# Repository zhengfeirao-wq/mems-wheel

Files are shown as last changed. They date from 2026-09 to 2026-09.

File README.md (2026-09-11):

# Tactile500 — 四板触觉采集系统（500 Hz / PyUSB）

500 Hz 四通道触觉传感采集系统，用于 AgiBot G1 机械爪。包含 **APM32F402 固件**与
**Python 上位机**两部分，通过 CH340 USB-UART 桥接，基于 V2 二进制协议通信。

---

## 仓库结构

```
.
├── upper_pyusb_500hz/        上位机：Python 库 + CLI + 浏览器监视界面
│   ├── src/tactile500/       核心库
│   ├── tests/                单元测试（含独立 C 编码向量）
│   ├── tools/                诊断与基准工具
│   ├── docs/                 接口、协议、发布说明
│   └── wheelhouse/           离线 wheel（tactile500 + pyusb）
│
├── firmware_tactile500/      APM32F402 固件
│   ├── Source/               应用逻辑（main / 传感器 / 协议 / 流控）
│   ├── Include/              配置与头文件
│   ├── Config/               DAL 板级配置
│   ├── Project/              Keil 工程（6 个板型 Target）
│   ├── docs/                 协议 V2、板型通道表
│   └── 烧录_OSR256_20260910/ 该档 OSR256 固件的 HEX 交付物与构建清单
│
├── outline/                  结构与点位
│   ├── 2d_sampling_points/   12 / 32 点传感器平面坐标（常量模块 + 原始 CSV + 坐标图）
│   └── 3d_structure/         夹爪三维结构（STEP / Blender / 可编辑预览 / 点位源）
│
├── docs/                     跨子项目文档
├── README_当前版本.md        版本入口索引
└── 今晚测试入口_嵌入式与wheel.md
```

---

## 硬件构型

四块独立采集板，每块通过一只 CH340（VID `1a86` / PID `7523`）接入主机：

| 板型 | 传感器点数 | 固件 identity | 说明 |
|---|---:|---|---|
| 左手 12 点（手指） | 12 | `0x08` | 无缆 |
| 右手 12 点（手指） | 12 | `0x09` | 无缆 |
| 左手 32 点（掌心） | 32 | `0x0E` | 短线 |
| 右手 32 点（掌心） | 32 | `0x0F` | 短线 |

另有长线旧版构型 `0x0C` / `0x0D`。

### 左右手如何区分

**左右手在烧录时确定，不是上电后自适应的。** `TACTILE_PROFILE` 是编译期宏，
由 Keil Target / GCC 构建目录选定，进而决定帧内的 `identity` 字节：

```
bit0    : 0=左手  1=右手
bit1    : 0=12点  1=32点
bit2    : 0=长线  1=短线（12点板恒为 0）
bit7:3  : 映射版本（当前 = 1）
```

固件每帧都携带该字节，上位机据此解出 `frame.role`
（`left_fingers` / `right_fingers` / `left_palm` / `right_palm`），
**不依赖 USB 端口位置**。USB 拓扑仅用于打开设备与诊断。

> ⚠️ 若把左右手固件烧反，上位机不会报错——它会按 USB 端口位置分配角色，
> 而 `identity` 会自相矛盾。现场联调时应用 `tactile500 scan` 核对该字节与物理位置。

---

## 协议要点（V2 / wire version `0x21`）

```
A5 5A | len | version | identity | status | sequence |
sample_time_us | fresh_mask | 温度×N(2B) | 压力×N(3B) | CRC16

12 点帧 =  80 字节      32 点帧 = 180 字节
UART   = 921600 8N1     帧率     = 500 Hz（周期 2 ms）
```

固件为**纯单向广播**：上电、等待约 1 秒完成传感器初始化，随后自动连续发送，
**不接收任何命令**（无握手、无校准写入）。

---

## 安装与运行（上位机）

主机需已安装 `libusb-1.0`。示例在新目录中执行，**不要覆盖机器人本体应用的虚拟环境**：

```bash
python3 -m venv .venv
.venv/bin/python -m pip install --no-index --find-links wheelhouse tactile500==0.4.2

.venv/bin/tactile500 scan                      # 只枚举，不打开设备
.venv/bin/tactile500 probe --seconds 30        # 收帧并报告实际速率
.venv/bin/tactile500 capture --seconds 1800 --output captures/run001
.venv/bin/tactile500 inspect captures/run001
.venv/bin/tactile500 view --bind 0.0.0.0 --port 8875 --output-root captures
.venv/bin/tactile500 view --simulate           # 无实物时的四板模拟
```

高速读取在已打开的 libusb1 后端上预提交 32 个异步 Bulk IN 请求。
该适配层使用 PyUSB 内部结构，**依赖固定为 `pyusb==1.3.1`**；
升级前须重新验证。同步读取可用于诊断对照：`TactileSystem(usb_io="sync")`。

---

## 接入上层系统

```python
from tactile500 import TactileSystem

system = TactileSystem()
native = system.subscribe(capacity=8192)
system.open()
try:
    while True:
        item = native.get(timeout=1.0)
        frame = item.frame
        # frame.role: left_fingers / right_fingers / left_palm / right_palm
        consume(frame.role, frame.sequence, frame.sample_time_us,
                frame.temperature, frame.pressure, frame.fresh_mask,
                item.host_read_end_ns)
finally:
    system.close()
    native.close()
```

需要同一时刻的四板快照时使用 `system.snapshots(hz=500, delay_seconds=0.004)`，
其状态为 `updated / reused / stale / missing / offline / ambiguous`。
快照采用同一主机单调时钟，不插值、不使用未来数据。

**单位说明**：`temperature` 为 0.1 °C；`pressure` 为旧固件的有符号 `raw * 9 / 80` 尺度，
**未经标定，不应称为 Pa 或 N**。

完整接口见 [`upper_pyusb_500hz/docs/API_AND_INTEGRATION.md`](upper_pyusb_500hz/docs/API_AND_INTEGRATION.md)，
二进制格式见 [`PROTOCOL_AND_RECORDING.md`](upper_pyusb_500hz/docs/PROTOCOL_AND_RECORDING.md)。

---

## 已知限制

以下为实测确认的边界，**读取与判别接口稳定可用**，但这些现象客观存在：

### 1. ~~`fresh_mask` 恒为 0~~ —— **已在 v3 固件修复**

> **状态更新（2026-09-11）：已修复并实机验证。** 四板 88 个通道全部恢复，
> `init_error` 归零，`fresh ≈ 0.5`（健康值）。详见
> [`firmware_tactile500/docs/DRDY修复与v3自愈记录.md`](firmware_tactile500/docs/DRDY修复与v3自愈记录.md)。
> 以下保留原分析作为背景。

原固件中 100% 的帧带 `not_all_fresh` 状态，`per_channel_fresh_fraction` 全为 0。
这意味着固件的 DRDY 轮询取不到「新转换」证据。

**这不等于断线或读数无效。** 判定依据是 `status` 的其它位：

| `fresh_mask` | `status` 其它位 | 含义 |
|---|---|---|
| 0 | 仅 `not_all_fresh` | SPI 通、传感器无故障、初始化成功；仅缺新鲜度证据 |
| 0 | 含 `spi_error` | SPI 通信故障 |
| 0 | 含 `sensor_error` | 传感器报故障（`ready & 0xFC`） |
| 0 | 含 `init_error` | 上电配置回读失败 |

**根因**：原固件初始化末尾写 `0xA5 = 0x88`，把 bit7 `DAC_on` 置 1。
按 NSA2302 datasheet Rev1.2 第 11 页，该位为 *Enable voltage output mode*；第 17 页 6.3 节说明
`DAC_on=1` 即进入 **analog output mode**（"no matter what 'CMD' registers contents"），
自主执行 64 次压力 + 1 次温度转换；而第 18–19 页 6.5.1 节的 INT/DRDY 行为只在
**命令驱动**的四种工作模式下定义。该模式不属于其中，故 DRDY 永不置位。

另有一个叠加因素：板载 EEPROM 被早期固件烧入了 `0xA5 = 0x88`，
上电自动加载后若固件的 `0xA5 = 0x08` 写入未生效，芯片会退回模拟输出模式，
此时 `0x30` 触发命令被忽略 —— v3 用**运行中自愈**（连续 4 帧 DRDY=0 即重写配置）解决。

**修复要点**：保持 `DAC_on=0`，改用 `0x30` COMMAND 寄存器触发单次转换，
做流水线采集（读完即触发下一轮，转换在帧间隔内完成），SPI 提至 3.75 MHz。
**协议与上位机均无需改动。**

### 2. `fresh ≈ 0.5` 是真实转换能力的反映，不是缺陷

NSA2302 在单次转换模式下一次完整转换（含每次 power-up）耗时 **2~4 ms**。
在 500 Hz 帧率下，因此每两帧才有一个真实新测量 —— `fresh` 比例约为 **0.5**。

这解释了早期"模拟输出模式"为何能到 ~489 次/秒：那是**自主连续转换、无每次上电开销**，
但代价是 DRDY 永不置位。**两者是本质权衡。**

若要每帧都是真实新测量，可把帧率降到 250 Hz；当前设计保留 500 Hz 帧率并用
`fresh_mask` 如实标记哪一帧是新数据。

### 3. 通道存在偶发满量程跳变

左手 12 点板（`identity 0x08`）的 **ch6** 出现 `±943718` 的跳变
（≈ 24 位满量程的符号异常），极差达 1,887,436。其余三板无此现象。

**软件基线扣除（校零）无法解决此问题**——已实测验证，减去静置均值后极差
改善率为 **0.0%**。因为校零只能平移波形，不能压缩幅度。该校零处理更适合
消除通道间静态偏置与温漂基线，不是此类数字异常的解法。

### 4. Hub 供电共担

Hub 由机器人 USB 总线供电。软件可隔离单设备通信故障，
**无法阻止物理短路导致整个 Hub 掉电**；如需该级别的故障隔离，
需要具备逐端口限流保护的供电硬件。

### 5. 跨板时间戳不可直接相减

MCU 时间戳各自从上电开始计。本版本固件不接收启动命令，
因此软件**无法让独立 MCU 的 ADC 硬件同时启动**。
4 ms 快照延迟提供选择缓冲，但不消除 USB 调度抖动或传感器转换相位差。

### 6. 平台验证范围

性能验证针对 **Ubuntu aarch64**（AgiBot G1 实机，Python 3.10）。
Windows USB 后端未验证。

---

## 测试

```bash
cd upper_pyusb_500hz
python -m pytest -q
```

覆盖独立 C 编码向量、CRC/碎片/噪声恢复、序号与时间戳回绕、
四板故障与换口、快照因果性、慢消费者与录制损坏检查。

固件侧另有 6 种板型的 GCC/Keil 双构建与 C 核心向量测试，
以及 12 份 HEX 的校验和 / Flash 范围 / 启动与中断向量检查。

---

## 部署到 AgiBot G1

```bash
cd ~
python3 -m venv .venv
.venv/bin/python -m pip install --no-index --find-links wheelhouse tactile500==0.4.2

.venv/bin/tactile500 scan
.venv/bin/tactile500 view --bind 0.0.0.0 --port 8875 --output-root captures
```

随后在 Windows 浏览器打开 `http://<G1地址>:8875`。

> G1 的当前日历时钟与工作电脑日期可能不一致。UTC 字段保留 G1 原始值；
> 所有速率、超时与软件对齐均使用单调时钟，不依赖该日历时间。

---

## 来源与许可

固件基于 Geehy APM32F4xx DAL 示例；厂商许可条款见
`firmware_tactile500/` 内相关声明文件。CH340 控制传输序列与传输基础类
来自已归档的旧版上位机项目；V2 解析、自动发现、故障隔离、快照与录制
为本项目实现。

本 Python 库**不依赖机械臂/机器人控制 SDK，也不发送运动命令**。

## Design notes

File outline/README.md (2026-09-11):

# outline

触觉夹爪的**二维采样点**与**三维结构模型**。

| 子目录 | 内容 |
|---|---|
| [`2d_sampling_points/`](2d_sampling_points/) | 12 点板 / 32 点板的传感器平面坐标：常量模块、原始 CSV、坐标图（PNG + Markdown）、绘图脚本 |
| [`3d_structure/`](3d_structure/) | 夹爪三维结构：STEP 结构件与装配体、Blender 模型与渲染图、可编辑预览（HTML/three.js）、几何校验数据 |

---

## 2d_sampling_points

传感器在平面上的采样点坐标，**12 点板与 32 点板各一套**。

| 文件 | 说明 |
|---|---|
| `sensor_coords.py` | **坐标常量模块**，上位机与可视化直接 `import`，无需解析 CSV |
| `coord_Big_raw.csv` | 32 点板原始坐标（`sensor_Number, X_coord, Y_coord`） |
| `coord_Small_raw.csv` | 12 点板原始坐标 |
| `传感器坐标图.md` | 坐标图文档：嵌入 PNG + 纯文本 ASCII 坐标图 + 逐行坐标表 + 结构分析 |
| `coord_plot_all.png` | 总览：两板单图 + 同坐标系叠加 |
| `coord_plot_big32.png` / `coord_plot_small12.png` | 单板大图 |
| `make_sensor_coords.py` | 生成器：CSV → `sensor_coords.py`（数值逐字照抄） |
| `plot_coords.py` | 绘图：常量 → PNG，并校验等比例与说明框不遮挡数据点 |
| `make_coord_md.py` | 生成器：常量 → `传感器坐标图.md` |

### 坐标约定

* **每块板的左下角 = (0, 0)**，Y 轴向上。平移量 = 该板自己的 `(x_min, y_min)`，**只平移，不缩放、不旋转、不镜像**。
* 两块板用的是同一套规则，因此对齐到同一原点后可以直接比较尺寸与节距。
* 原始绝对坐标（与 CSV 逐字一致）保留在 `sensor_coords.py` 的 `*_COORDS` / `*_XY` 里。

| 板 | 点数 | 平移量 | 原点化尺寸 宽 × 高 |
|---|---:|---|---|
| Big 32 点 | 32 | (127.531, 55.6552) | 42.4614 × 27.5869 |
| Small 12 点 | 12 | (105.8507, 71.1159) | 11.3550 × 29.9387 |

### 用法

```python
from sensor_coords import xy_rel_for, coords_rel_for, normalized_xy, size_for

xy_rel_for(17, 32)    # -> (0.0, 0.0)        Big 板左下角
xy_rel_for(23, 32)    # -> (42.4614, 8.975)  最远点
coords_rel_for(12)    # -> Small 板整张表
normalized_xy(32)     # -> {通道号: (u, v)}，u = X/宽, v = Y/高
normalized_xy(32, y_up=False)   # v=0 在上，屏幕坐标直接乘控件高度即可
```

重新生成（Python 3.10+，需要 matplotlib）：

```powershell
python make_sensor_coords.py     # CSV  ->  sensor_coords.py
python plot_coords.py            # 常量 ->  PNG（左下角 = (0,0)）
python plot_coords.py --raw      # 常量 ->  PNG（原始绝对坐标）
python plot_coords.py --flip     # 常量 ->  PNG（Y 轴向下）
python make_coord_md.py          # 常量 ->  传感器坐标图.md
python sensor_coords.py          # 常量模块自检
```

`plot_coords.py` 会逐面板校验**等比例**（`ratio` 必须为 `1.0000`）与**说明框是否遮挡数据点**（必须为 0 个）。

坐标数据源自 [`3d_structure/editable_gripper_preview/coordinates/`](3d_structure/editable_gripper_preview/coordinates/)，两处 `coord_*_raw.csv` 内容一致。

---

## 3d_structure

夹爪三维结构模型与可编辑预览。

| 项 | 说明 |
|---|---|
| `onebody-12-jiegoujian.STEP` / `onebody-32-jiegoujian.STEP` | 12 点 / 32 点结构件 STEP |
| `editable_gripper_preview/cad/12`、`cad/32` | 分件 STEP：结构本体、硅胶帽、盖板、连接器、PCB 示意，含装配体与爆炸图 |
| `editable_gripper_preview/blender/` | Blender 源文件（`.blend`）、`.glb` 与渲染 PNG |
| `editable_gripper_preview/gripper-preview.html` | 可交互三维预览（three.js，单文件、离线可用） |
| `editable_gripper_preview/mesh-data.json`、`geometry-validation.json` | 网格数据与几何校验结果 |
| `editable_gripper_preview/build_models.py`、`build_preview.py`、`verify_cad.py` | 建模与校验脚本 |
| `自适应通用夹爪传感器说明书.pdf` | 传感器说明书 |
| `baseline-manifest.json`、`README.md` | 基线清单与说明 |

### 打开预览

直接双击 `editable_gripper_preview/gripper-preview.html`（或拖进浏览器）即可，依赖已内置于 `vendor/`。

### 重新构建

```powershell
cd editable_gripper_preview
pip install -r requirements-cad.txt
python build_models.py
python build_preview.py
```

```powershell
python verify_baseline.py          # 校验基线清单
python editable_gripper_preview/verify_cad.py
```

---

## 备注

* 本目录按仓库 `.gitignore` 的规则**强制加入**了 `*.csv` 与 `__pycache__/`：前者是坐标数据源（必须入库），后者是 Python 编译缓存（如需清理见下）。
* 清理编译缓存：

  ```powershell
  git rm -r --cached outline/3d_structure/__pycache__ outline/3d_structure/**/__pycache__
  ```

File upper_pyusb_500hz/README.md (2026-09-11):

# Tactile500 V2 PyUSB 上位机（0.4.2）

**最新交接入口（2026-09-10）：[安装、接口示例与已知边界](../out/04_wheel交接/联调说明.md)，[两档数据和CH12报告](../out/README.md)。交接wheel仍为0.3.0，OSR256在固件侧设置；原始wheel未重打包。今晚有一次USB重新枚举后需要重启采集服务恢复，真实Hub热插拔尚不能承诺全部自动恢复。**（后续进展：0.4.1 交付软件校零 `tare.py`，0.4.2 起提供 `tare` 命令行，见 `docs/TARE.md`。）

面向 G1 Ubuntu / Python 3.10 的四板触觉采集库。仅通过 PyUSB + libusb 访问 CH340
（VID `1a86` / PID `7523`），不依赖 ttyUSB、pyserial 或 ch341 内核模块。

**今晚测试入口：[四板查看与 wheel 交付](docs/RELEASE_0_3_0.md)。**
同一 wheel 提供 Python API、命令行原始采集，以及可选的 Windows 浏览器四板界面。
界面以10Hz读取缓存，原始采集和录制按板卡实际帧率运行。未启动 view 时不启动HTTP线程。

当前协议：`A5 5A` V2，12 路 80 字节，32 路 180 字节。旧 `BT` 数据不能直接混入 V2。
V2 修订 `0x21` 修复了 APM32F402 普通 DMA 通道未关闭导致的约 125Hz 发送问题。
配套固件在相邻目录 `嵌入式代码/Applications/Tactile500`。

## 安装与运行

这是 `py3-none-any.whl`，可安装到 Ubuntu aarch64；机器需要已有 `libusb-1.0`。
高速读取在 PyUSB 已打开的 libusb1 后端上预提交 32 个异步 Bulk IN 请求，避免 Python
解析期间没有在途 USB 请求。此适配层使用 PyUSB 内部结构，依赖固定为 `pyusb==1.3.1`。
升级 PyUSB 前须重新验证该适配层；同步 PyUSB 读取可用 `TactileSystem(usb_io="sync")`
作诊断对照。本次性能验证针对 Ubuntu aarch64，未验证 Windows USB 后端。
本次 G1 实机已确认 libusb 可用、CH340 未绑定内核驱动、普通用户有 USB 访问权限。
不要覆盖现有机器人应用的虚拟环境。示例在一个新目录执行：

```bash
python3 -m venv .venv
.venv/bin/python -m pip install --no-index --find-links wheelhouse tactile500==0.4.2
.venv/bin/tactile500 scan
.venv/bin/tactile500 probe --seconds 30
.venv/bin/tactile500 capture --seconds 1800 --output captures/run001
.venv/bin/tactile500 inspect captures/run001
.venv/bin/tare --seconds 2 --note "第 1 天开机"   # 夹爪张开、无接触时采一次零点
# G1 上运行，Windows 访问 G1 当前地址的8875端口：
.venv/bin/tactile500 view --bind 0.0.0.0 --port 8875 --output-root captures
# 无实物时的四板模拟，界面明确标示模拟数据：
.venv/bin/tactile500 view --simulate
```

`tare` 是 0.4.2 起的独立命令（软件校零，`src/tactile500/tare.py`）：采一次静止基线、
打印零点 JSON、追加写入 `~/.tactile500/tare/journal.jsonl`。用法与退出码见
[docs/TARE.md](docs/TARE.md)。

`wheelhouse/` 同时提供本库和 PyUSB wheel。`scan` 只枚举；`probe/capture` 会配置
CH340 的 921600 8N1 和 DTR/RTS，然后读 Bulk IN，不向 MCU 发送启动或控制命令。
采集目录必须不存在，以防覆盖历史数据。Ctrl+C 会停止读取并排空录制队列。

若系统已有内核驱动或另一程序占用接口，本库报告该设备错误并持续重试，其他板继续工作。
权限配置属于实际操作系统部署事项；无需安装串口驱动，不自动抢占接口或复位 USB Hub。

## 接入大系统

原始帧订阅保持板子的真实发送频率。所有数组默认都是**固件已经排列好的通道顺序**。

```python
from tactile500 import TactileSystem

system = TactileSystem()
native = system.subscribe(capacity=8192)
system.open()
try:
    while True:
        item = native.get(timeout=1.0)
        frame = item.frame
        # frame.role: left_fingers / right_fingers / left_palm / right_palm
        consume(frame.role, frame.sequence, frame.sample_time_us,
                frame.temperature, frame.pressure, frame.fresh_mask,
                item.host_read_end_ns)
finally:
    system.close()
    native.close()
```

上层需要同一时刻的四板快照时：

```python
from tactile500 import TactileSystem

with TactileSystem() as system:
    for snapshot in system.snapshots(hz=500, delay_seconds=0.004):
        for role, slot in snapshot.slots.items():
            # state: updated / reused / stale / missing / offline / ambiguous
            if slot.value is not None:
                consume_snapshot(snapshot.target_ns, role, slot.state,
                                 slot.value.frame, slot.age_ns)
```

快照采用同一主机单调时钟，挑选目标时刻之前最近收到的帧，不插值、不用未来数据。
慢消费者跳过过期快照，`skipped_ticks` 记录跳过数量，不补发密集的历史快照。
`receive_skew_ns` 是选中帧的主机接收时间差，不是 ADC 采样同时性的证明。
MCU 的时间戳各自从上电开始，不能直接跨板相减；本版本没有 MCU 接收启动命令，
因此软件不能让独立 MCU 的 ADC 硬件同时启动。4ms 的快照延迟提供选择缓冲，
不能消除 USB 调度抖动或传感器自身转换相位差。

`frame.temperature` 单位为 0.1°C；`frame.pressure` 保留旧固件的有符号 `raw * 9 / 80`
尺度，未经额外标定不称为 Pa 或 N。`fresh_mask` 仅表示读取前看到了 DRDY 且读取成功。
实测修订 0x21 的连续 DAC 模式能读到变化数值，但 DRDY 始终为 0，因此该位当前无法证明
每个通道 500 次/秒新转换；0 不自动等于断线或读数无效。温度在此模式下刷新较慢。
硬件错误查看 SPI、sensor、init 位；主机断线/过期状态单独在 `system.status()` 中报告。

`TactileHand` 是 `TactileSystem` 的别名，便于使用旧入口名称。数据结构已改为 V2，
不承诺与旧 DeepSeek 的帧对象或 T500 录制格式兼容。完整接口见
[API_AND_INTEGRATION.md](docs/API_AND_INTEGRATION.md)。

## 自动识别、换口与隔离

- 从帧身份字节识别四个角色：左/右手 × 12/32 路；短/长线和映射修订随帧保留。
- USB 拓扑只用于打开设备和诊断。换 Hub 口后重新识别，不把旧口号当角色。
- 同角色两块板同时在线时报告 `ambiguous`，不任意选一块供上层使用；原始帧仍按路径录制。
- 每个设备独立 USB 读取线程和解析线程；持续重连，单板打开失败或拔出不停止其他板。
- 输入、订阅和录制队列均有上限；超过上限公开记录丢弃数量，不阻塞其他采集。
- Hub 当前由机器人 USB 总线供电。软件可以隔离单设备通信故障，无法阻止物理短路导致
  整个 Hub 掉电；若要求这种故障也隔离，需要具有逐端口限流保护的供电硬件。

32 路短线物理位置表沿用用户已确认的旧上位机表。调用
`tactile500.mapping.physical_values(frame)` 会同时变换温度、压力和 fresh 位。
长线物理布局未确认时拒绝自动转物理位置，仍可正常接收其固件通道顺序。
不要再次应用 MCU 的片选排列。

## 录制、测试与来源

录制文件保存原始 V2 字节、CRC、序号、MCU 时间戳以及主机读取时间。
`session.json` / `report.json` 保存丢包、坏帧、队列丢弃和运行状态。
起始截断候选与稳定流中的坏帧分别计数。G1 当前日历时钟与工作电脑日期不一致，
UTC 字段保留 G1 原始值；所有速率、超时和软件对齐都使用单调时钟，不依赖该日历时间。
具体二进制格式见 [PROTOCOL_AND_RECORDING.md](docs/PROTOCOL_AND_RECORDING.md)。

```bash
python -m pytest -q
python -m pip wheel --no-build-isolation --no-deps . -w wheelhouse
```

测试包括独立 C 编码向量、CRC/碎片/噪声恢复、序号与时间戳回绕、四板故障和换口、
快照因果性、慢消费者和录制损坏检查。实物结果与限制见 `reports/` 和验收报告。
四板模拟不能替代四块实物同时运行；已先后测试左12/左32短线和右12/右32长线两套。
OSR2048与OSR256的60秒主对比均来自同一套右12/右32长线，完整证据在上面的out入口。

来源：CH340 控制传输序列和传输基础类来自已归档的
`备份/旧版上位机/deepseek-tactile500_pyusb上位机`（相对本工作区主目录），
协议依据本项目 V2 固件；V2 解析、自动发现、故障隔离、快照与录制实现位于此目录。
原 DeepSeek 项目未被修改。该 Python 库不依赖机械臂/机器人控制 SDK，也不发送运动命令。

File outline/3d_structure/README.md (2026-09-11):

# 触觉夹爪模型 · 当前唯一版本

保留版本：**2026-09-08，房顶朝上、柔性导线伸直修正版**。PCB 与传感器已按两份 CSV 的实际 XY 相对位置重建，12 通道为 3/3/2/2/2 五排；胶层接触平面延伸至尖端的设计保留。12 通道和 32 通道是同一版本的两个型号，初始展示均为房顶朝上，导线按伸直状态表示。

- [HTML 爆炸图](editable_gripper_preview/gripper-preview.html)：离线打开，默认 32 通道、80% 爆炸程度，可切换型号。
- [Blender / SolidWorks / Python 调用说明](editable_gripper_preview/interface/README.md)：其他建模项目从这里接入。
- [机器可读接口清单](editable_gripper_preview/interface/manifest.json)：零件 ID、相对路径、单位、坐标、爆炸位移及原始文件校验值。
- [模型说明](editable_gripper_preview/README.md)：文件用途、模型依据与验证范围。

## 原始资料

`onebody-12-jiegoujian.STEP`、`onebody-32-jiegoujian.STEP` 和 `自适应通用夹爪传感器说明书.pdf` 保存在本目录；PCB 原始参考图保存在 `editable_gripper_preview/reference-pcb.png`。

搬迁或提供给其他项目时，复制整个 **（7）3D建模** 目录，保留相对路径。HTML 已内嵌模型，可以单独复制；重新建模和完整接口调用应使用整个目录。

目录只保留当前模型、原始资料、当前格式导出、必要的生成代码与接口验证文件。旧版备份、旧压缩包、修改前后对比图和临时检查产物已移入 Windows 回收站。

## 已确认的起始基准

当前文件作为后续项目的起始材料。`baseline-manifest.json` 记录文件 SHA-256；运行 `python verify_baseline.py` 可检查是否被改动。后续新设计应另存版本，不覆盖本基准。基准校验保证文件一致性；原说明中的单位、绝对安装基准和硬件接线待核实项仍适用。

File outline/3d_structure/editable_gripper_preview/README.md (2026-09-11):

# 触觉夹爪 · 尖端房顶方向修正版

当前版本为 `2026-09-08-csv-relative-layout`，包含 12 / 32 通道两个型号。两种型号的 HTML 初始视角和 Blender 保存视角均为房顶朝上；四根柔性导线按伸直状态展示。封装尖端定义为房顶（原始 CAD +Y）。传感器 XY 相对位置以 coordinates/ 下两份原始 CSV 为准，不以序号决定位置。32 通道按 Y 从大到小为 1 / 7 / 6 / 6 / 6 / 6，12 通道为 3 / 3 / 2 / 2 / 2；排间距与横向错位均保留。封装胶层安装端保留随形弧面，源坐标 Y=21.3 mm 到末端的外接触面保持同一平面；当前外表面 Z=0.2 mm。末端背面按原结构斜边贴合，局部胶厚随之变化。

## 直接使用

| 用途 | 文件 |
| --- | --- |
| 离线 HTML 爆炸图 | `gripper-preview.html` |
| 爆炸图静态图片 | `preview-12-exploded.png`、`preview-32-exploded.png` |
| Blender 原生文件 | `blender/gripper-12.blend`、`blender/gripper-32.blend` |
| 通用三维网格 | `blender/gripper-12.glb`、`blender/gripper-32.glb`，保存装配状态 |
| SolidWorks / CAD 总装 STEP | `cad/12/gripper-12-assembled.step`、`cad/32/gripper-32-assembled.step` |
| CAD 爆炸状态 STEP | 各型号目录内的 `gripper-*-exploded.step` |
| 单独结构件、胶层等 | 各型号目录内的 `Structural_body.step`、`Source_cover.step`、`Silicone_cap.step`、`PCB_illustrative.step`、`Connector_illustrative.step` |
| 其他项目调用入口 | [interface/README.md](interface/README.md) 与 [manifest.json](interface/manifest.json) |

Blender 文件中的 `Gripper_12` / `Gripper_32` 为父对象，其自定义属性 `explode` 范围为 0～1，默认 0.8。0 为装配状态，1 为完全展开。每个零件都是可单独操作的对象，保留名称、材料、分类与原 CAD 坐标关系。

## 模型依据

1. 原始两份 STEP 各含两个结构实体；主体和第二结构实体直接复用源几何。第二实体的实物名称尚未确认。
2. 黄色胶层是新增设计；名义厚度 2.2 mm、边缘内收 0.25 mm、上端起点 Y=1.3 mm 为当前参数，未做实物测量。内表面裁切贴合主体，属于变厚度封装。
3. 硅胶按贴附/粘接关系表达，本模型不另建胶水层或胶缝。
4. 32 通道按 CSV 分为 1+7+6+6+6+6，12 通道为 3+3+2+2+2；传感器中心的 XY 相对位置来自 CSV。CSV 未给单位与安装基准：当前统一按 1 坐标单位=1 mm，X 居中、最大 Y 平移至 CAD Y=33.5 mm，无旋转、镜像、分别缩放或吸附。Z 随结构曲面推定，PCB 支撑和器件尺寸为示意。PCB 厚度、器件封装和线缆尺寸尚未实物验证。
5. 爆炸方向用于展示层次，不代表真实拆卸路径；电子组件未做完整制造及装配干涉校核。
6. STEP 保留具名实体/组件，不包含原生 SolidWorks 草图特征历史。Blender / GLB 是网格，精确 CAD 曲面操作应使用 STEP。

## 源文件与重新生成

原始 STEP 和说明书保留在上一级目录，PCB 原始参考图为 `reference-pcb.png`。

- `parameters.json` / `build_models.py`：当前 CAD 生成参数和建模源代码。
- `preview.template.html` / `build_preview.py`：HTML 源模板与生成器。
- `mesh-data.json`：当前 CAD 的显示网格，供 HTML 和 Blender 共用。
- `vendor/`：离线 Three.js 与许可文件。

只更新页面时运行 `python build_preview.py`，它读取已确认的网格，不重画模型。修改模型参数后使用 Python 3.12 与 `requirements-cad.txt` 中的 CadQuery 依赖运行 `python build_models.py`，再按接口文档重建 Blender / GLB 并验证。不要手工修改 STEP 或生成的 HTML。

## 已验证与未验证

- 点位：验证实际 CAD 器件中心及导出网格与 CSV 对应，核对全部 66 / 496 对 XY 距离；序号只用于追溯数据来源。
- CAD：两种胶层均为单个有效实体，与主体重叠体积为 0；下部外表面为 CAD `PLANE`，31 截面检查误差约 1×10⁻⁷ mm。6 个胶层/装配/爆炸 STEP 已重新导入检查。
- Blender 5.2.1 LTS：两种 `.blend` 保存后重开、GLB 导出后回读、零件数量及名称、材料、坐标、爆炸位移和米/毫米场景均通过检查。导入函数保留已有场景对象。
- HTML：型号切换、爆炸程度、显隐、透明度、视角、PNG 导出、窄屏和调用接口已检查，无页面脚本异常。
- SolidWorks：已提供官方 STEP API 对应的 PowerShell / VBA 调用入口，路径解析已验证；本机未安装 SolidWorks，尚未完成 SolidWorks 实机运行或原生 `.SLDPRT` / `.SLDASM` 保存验证。
- 本机临时 CadQuery 环境有既存的退出清理异常；CAD 文件已另外重读确认有效。重建 CAD 时建议使用独立依赖环境。

CAD 检查记录见 `geometry-validation.json`、`step-roundtrip-validation.json`；接口和 Blender 检查记录见 `interface/*-validation.json`。这些检查不替代实物测量或制造公差验收。

点位源文件在 `coordinates/`，生成入口为 `sensor_layout.py`；`coordinate-layout.svg` 为无编号等比例点位图。`parameters.json` 中的坐标比例与整体 Y 定位是显式展示假设。

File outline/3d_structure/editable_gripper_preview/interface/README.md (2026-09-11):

# Blender / SolidWorks / Python 调用接口

唯一模型版本：`2026-09-08-csv-relative-layout`。`AssetRoot` 指 `editable_gripper_preview` 目录。其他项目传入这一根目录即可；`manifest.json` 内全部资产路径相对于 `AssetRoot`，不依赖当前工作目录。

两种型号初始展示均为房顶朝上，柔性导线伸直。展示朝向由相机控制，CAD / GLB 坐标约定保持一致。

## 数据约定

- 型号：`12` 或 `32`，分别有 23 / 43 个具名组件，器件数量为 12 / 32。
- 房顶方向：封装尖端为原始 CAD +Y。两型号 XY 点位直接来自 CSV，编号只为来源标识，不决定排列。CSV +Y 映射到 CAD +Y，默认展示向上。
- 精确曲面：STEP，单位 mm，保持原始 STEP 的 XYZ 右手坐标。
- 爆炸参数：Python / Blender 使用 0～1，HTML 使用 0～100%。0 均为装配状态。
- 爆炸位移：清单中的 `explode_translation_cad_mm` 是完全展开时在 CAD 坐标中的平移向量；单件 STEP 保持装配位置。
- 浏览器显示变换：`preview=(-CAD.x, 14-CAD.y, CAD.z+12)`。`model_api.load_mesh()` 已转换回原始 CAD 坐标，不要再旋转一次。
- Blender 导入按当前场景的实际单位比例将 mm 换成场景单位。所有零件挂在一个父对象下，移动父对象即可与其他模型装配。
- GLB 保存装配状态，单位为米，按 glTF 标准 Y 向上导出；Blender 标准导入器会恢复坐标方向。

稳定零件 ID：`Structural_body`、`Source_cover`、`Silicone_cap`、`PCB_illustrative`、`Solder_pads_illustrative`、`Connector_illustrative`、`Connector_pins_illustrative`、`Sensor_01_illustrative` …、`Wire_1_illustrative` …。传感器、焊盘、端子和线缆在总装 STEP 内是具名组件；单独 STEP 是否存在以清单的 `step_file` 为准。

## Blender：添加到已有场景

```python
from pathlib import Path
import sys

assets = Path(r"D:\2026\2026-1-THU-G1-mems_tactile_repeatedExperiments\（7）3D建模\editable_gripper_preview")
sys.path.insert(0, str(assets / "interface"))
from import_blender import import_model, set_explode, export_glb

module = import_model(channel=32, explode=0, asset_root=assets)
module.location = (0.2, 0, 0)  # 当前 Blender 场景单位
set_explode(module, 0.8)
silicone = next(o for o in module.children if o["part_id"] == "Silicone_cap")
# export_glb(module, r"D:\OtherProject\gripper.glb")
```

`import_model()` 不清空已有场景，不修改场景单位，返回父 Empty。子对象有稳定的 `part_id` 自定义属性；即使重复导入导致 Blender 给名字加 `.001`，仍可通过该属性查找。爆炸驱动控制子对象位置，整体定位使用父对象。

不写代码时，直接打开 `../blender/gripper-32.blend`；也可在其他 Blender 文件中通过 **File → Append** 追加它的 `Gripper_32` Collection。父对象的自定义属性 `explode` 已保存驱动关系。

命令行导入（`blender.exe` 换成实际安装路径）：

```powershell
$assets = 'D:\2026\2026-1-THU-G1-mems_tactile_repeatedExperiments\（7）3D建模\editable_gripper_preview'
blender.exe --background --factory-startup --python-exit-code 1 --python "$assets\interface\import_blender.py" -- --channel 32 --explode 0.8 --save 'D:\OtherProject\gripper.blend'
```

## SolidWorks：STEP 导入

需要本机安装并激活 SolidWorks。PowerShell 脚本按清单解析路径，调用 `GetImportFileData` → `MapConfigurationData=True` → `LoadFile4`，返回 `ModelDoc2` COM 对象；不自动覆盖或保存已有用户文件。

在 **Windows PowerShell 5.1** 中：

```powershell
$assets = 'D:\2026\2026-1-THU-G1-mems_tactile_repeatedExperiments\（7）3D建模\editable_gripper_preview'

# 只解析路径，无需安装 SolidWorks。
& "$assets\interface\Import-SolidWorks.ps1" -Channel 32 -State assembled -ResolveOnly

# 打开完整装配。
$doc = & "$assets\interface\Import-SolidWorks.ps1" -Channel 32 -State assembled

# 打开爆炸 STEP 或只调用胶层。
# $doc = & "$assets\interface\Import-SolidWorks.ps1" -Channel 12 -State exploded
# $doc = & "$assets\interface\Import-SolidWorks.ps1" -Channel 32 -PartId Silicone_cap
```

VBA 入口位于 `ImportGripper.bas`。在 SolidWorks 宏编辑器中导入该模块，其他 VBA 代码可以调用：

```vb
Dim model As Object
Set model = OpenGripper(Application.SldWorks, AssetRoot, 32, "assembled")
' 只调用胶层：
' Set model = OpenGripper(Application.SldWorks, AssetRoot, 32, "assembled", "Silicone_cap")
```

如需直接运行模块的 `main`，将新建 `.swp` 保存到本 `interface` 目录，宏会自动查找根目录。STEP 的导入拓扑受 SolidWorks 设置影响，可能显示为装配体或多实体零件；可使用五类单件 STEP 建立装配。接口不生成原生草图特征树或原生爆炸配置。

本机未安装 SolidWorks：COM/VBA 路径尚未实机运行。STEP 已重新导入 CAD 内核检查，PowerShell 的清单及路径解析已测试。

## 普通 Python / 其他建模程序

`model_api.py` 只依赖 Python 标准库，返回 STEP 路径、独立网格和元数据：

```python
import sys
from pathlib import Path

assets = Path(r"D:\2026\2026-1-THU-G1-mems_tactile_repeatedExperiments\（7）3D建模\editable_gripper_preview")
sys.path.insert(0, str(assets / "interface"))
from model_api import get_step_path, load_mesh, list_parts, load_manifest

step = get_step_path(32, part_id="Silicone_cap", asset_root=assets)
assembly = get_step_path(32, state="assembled", asset_root=assets)
mesh = load_mesh(32, explode=0, units="mm", asset_root=assets)
parts = list_parts(32, asset_root=assets)
# mesh["parts"][i] 包含 id、vertices、triangles、分类和爆炸位移。
# CadQuery 可继续调用：cq.importers.importStep(str(step))
```

CLI：`python model_api.py --channel 32 --part Silicone_cap`。用 `--list-parts` 输出完整清单。

## HTML 调用

打开 `../gripper-preview.html`，在该页面上下文中：

```javascript
window.gripperPreview.setModel(32);
window.gripperPreview.setExplode(80); // 0～100，百分比
window.gripperPreview.setVisibility('silicone', true);
window.gripperPreview.setView('side'); // iso / front / back / side
window.gripperPreview.getState();
```

iframe 嵌入后直接访问 `contentWindow` 需要同源；本版不提供跨域消息协议。离线 HTML 已内嵌模型，展示不依赖 Blender、SolidWorks 或服务器。

## 重建与验证

只改 HTML：在 `AssetRoot` 运行 `python build_preview.py`。它从当前网格生成页面并更新接口清单。

修改几何参数后依次运行：

```powershell
python build_models.py
python verify_cad.py
blender.exe --background --factory-startup --python-exit-code 1 --python interface/build_blender_assets.py
node verify_preview.cjs
python interface/verify_delivery.py
```

CAD 使用 `requirements-cad.txt` 依赖，Blender 使用自带 Python。`verify_preview.cjs` 使用 Playwright，文件开头的依赖路径可按目标机器环境调整。`build_blender_assets.py` 会清空其运行进程的场景，只允许在新建的后台 Blender 进程运行；向已有场景添加模型使用 `import_blender.py`。

`blender-validation.json` 记录 Blender 版本、零件数量、坐标/爆炸误差及 `.blend`/GLB 回读结果。`delivery-validation.json` 核对相对路径、原始文件哈希、单位和坐标转换，并检查 Blender 产物是否对应当前网格。

接口依据：[Blender Mesh API](https://docs.blender.org/api/5.0/bpy.types.Mesh.html)、[Blender 单位定义](https://docs.blender.org/api/5.0/bpy.types.UnitSettings.html)、[SolidWorks STEP 导入 API 示例](https://help.solidworks.com/2024/english/api/sldworksapi/Import_STEP_File_Example_VB.htm)。

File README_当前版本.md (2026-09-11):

# 版本与入口索引

本仓库为 **Tactile500 四板 500 Hz 触觉采集系统**（固件 + PyUSB 上位机）。
完整介绍见 [README.md](README.md)。

## 当前版本

| 组件 | 版本 | 位置 |
|---|---|---|
| 上位机 | tactile500 **0.3.0** | [upper_pyusb_500hz](upper_pyusb_500hz) |
| 固件 | wire version **0x21**（OSR256） | [firmware_tactile500](firmware_tactile500) |
| 协议 | V2，帧头 `A5 5A` | [PROTOCOL_V2.md](firmware_tactile500/docs/PROTOCOL_V2.md) |

帧率 500 Hz；12 点帧 80 字节、32 点帧 180 字节；UART 921600 8N1。

## 快速入口

| 需求 | 打开 |
|---|---|
| 系统总览与架构 | [README.md](README.md) |
| 安装 wheel 与接口示例 | [API_AND_INTEGRATION.md](upper_pyusb_500hz/docs/API_AND_INTEGRATION.md) |
| 二进制协议与录制格式 | [PROTOCOL_AND_RECORDING.md](upper_pyusb_500hz/docs/PROTOCOL_AND_RECORDING.md) |
| **软件校零（tare）** | **[TARE.md](upper_pyusb_500hz/docs/TARE.md)** —— 采集前校零、原始值保留、漂移回溯 |
| **校零模块交付报告** | **[软件校零交付报告.md](docs/软件校零交付报告.md)** —— 需求/设计/接口/实机验证/边界，可直接用于系统文档 |
| 0.3.0 交付与启动步骤 | [RELEASE_0_3_0.md](upper_pyusb_500hz/docs/RELEASE_0_3_0.md) |
| 离线 wheel（含 PyUSB） | [upper_pyusb_500hz/wheelhouse](upper_pyusb_500hz/wheelhouse) |
| 四板烧录选型 | [先读我_四板首次烧录.md](firmware_tactile500/先读我_四板首次烧录.md) |
| OSR256 固件与烧录 | [先读我_OSR256烧录.md](firmware_tactile500/烧录_OSR256_20260910/先读我_OSR256烧录.md) |
| 板型与通道映射表 | [BOARD_VARIANTS_AND_CHANNEL_MAP.md](firmware_tactile500/docs/BOARD_VARIANTS_AND_CHANNEL_MAP.md) |
| Keil 工程 | [Tactile500.uvprojx](firmware_tactile500/Project/MDK/Tactile500.uvprojx) |
| 固件主程序 | [main.c](firmware_tactile500/Source/main.c) |

## 本仓库包含与不包含

**包含**：上位机源码 / 测试 / 工具 / 文档 / 离线 wheel；固件源码 / Keil 与 GCC 工程 /
板级配置 / 6 份烧录 HEX（左·右手 × 12·32 点 × 长·短线）。

**不包含**（体积原因，留在原始工作区）：历史 `reports/` 审计图、`out/` 汇报材料、
`备份/` 旧版归档、厂商 SDK、PCB 源文件与 3D 模型、采集数据与构建中间产物。
`.gitignore` 已排除这些类别，重新生成不会误入库。

## 已知限制

实测确认的边界详见 [README.md](README.md) 的「已知限制」章节，摘要如下：

1. **`fresh_mask` 恒为 0** —— DRDY 轮询取不到新转换证据；不等于读数无效，
   判定依据是 `status` 其它位（仅 `not_all_fresh` 表示链路正常）。
2. **左手 12 点板 ch6 偶发满量程跳变**（±943718）。软件校零无法解决（实测改善 0.0%）。
3. **Hub 供电共担** —— 无逐端口限流保护，物理短路会导致整 Hub 掉电。
4. **跨板时间戳不可直接相减** —— MCU 各自从上电计时。
5. **平台验证范围为 Ubuntu aarch64** —— Windows USB 后端未验证。

## 版本演进摘要

- **0.3.0** —— V2 协议、自动发现、故障隔离、四板快照、浏览器监视界面。
- **0.2.0** —— 早期实验版本，目录已归档。
- **0.1.0** —— 100 Hz 串口方案（pyserial），已被本 PyUSB 方案取代。

OSR 设置演变：OSR2048（对比基线） → **OSR256（当前）**。

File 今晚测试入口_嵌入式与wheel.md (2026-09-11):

# 测试入口：固件 0x21 + tactile500 0.3.0

一个 wheel 提供两种入口：Python 采集 API / CLI，以及 Windows 浏览器四板查看。
采集与原始录制保持每板实际 500 Hz 接收；查看约 10 Hz。

## 快速链接

1. **烧录工程**：[Tactile500.uvprojx](firmware_tactile500/Project/MDK/Tactile500.uvprojx)
2. **main.c**：[Source/main.c](firmware_tactile500/Source/main.c)
3. **按实物选 Target/HEX**：[四板烧录说明](firmware_tactile500/先读我_四板首次烧录.md)
4. **OSR256 固件与步骤**：[先读我_OSR256烧录.md](firmware_tactile500/烧录_OSR256_20260910/先读我_OSR256烧录.md)
5. **Python wheel**：[tactile500-0.3.0-py3-none-any.whl](upper_pyusb_500hz/wheelhouse/tactile500-0.3.0-py3-none-any.whl)
6. **启动与录制步骤**：[0.3.0 交付说明](upper_pyusb_500hz/docs/RELEASE_0_3_0.md)
7. **完整通信协议**：[PROTOCOL_V2.md](firmware_tactile500/docs/PROTOCOL_V2.md)

## 板型与 identity 对照

短线 = 新版，长线 = 旧版。左12、右12、左32短、右32短应分别显示 **08、09、0E、0F**。

| 板型 | identity | 帧长 |
|---|---|---|
| 左手 12 点 | `0x08` | 80 字节 |
| 右手 12 点 | `0x09` | 80 字节 |
| 左手 32 点短线 | `0x0E` | 180 字节 |
| 右手 32 点短线 | `0x0F` | 180 字节 |

## 在 G1 上启动

```bash
cd /home/agi/tactile500_release_20260910_03
.venv/bin/tactile500 scan
.venv/bin/tactile500 view --bind 0.0.0.0 --port 8875 --output-root captures
```

随后 Windows 打开 `http://<G1-IP>:8875`（把 `<G1-IP>` 换成机器人当前实际地址）。
也可执行上位机目录的[打开G1四板查看.ps1](upper_pyusb_500hz/打开G1四板查看.ps1)。
服务未启动时显示无法连接是正常的；无需重新安装或先运行旧版网页程序。

## 验收状态

四板模拟已测。实物测试结果与已知限制以仓库根目录
[README.md](README.md) 的「已知限制」章节为准，摘要：

- 每板约 500 Hz，序号缺口、稳态坏帧、USB 输入队列丢块、录制丢弃均为 **0**。
- `fresh_mask` 恒为 0（DRDY 取不到新转换证据），但各通道数值持续变化，数据有效。
- 左手 12 点板 ch6 存在 ±943718 偶发满量程跳变；软件校零无法解决。

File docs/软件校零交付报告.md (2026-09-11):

# 软件校零（Tare）模块交付报告

**项目**：Tactile500 四板 500 Hz 触觉采集系统
**模块**：上位机软件校零
**版本**：tactile500 **0.4.1**
**交付日期**：2026-09-11
**代码仓库**：https://github.com/zhengfeirao-wq/mems-wheel
**提交**：`2aed6c2`（本地与远程一致）

---

## 一、需求

系统集成方（采集系统）提出三点要求：

| # | 要求 | 说明 |
|---|---|---|
| 1 | **输出值接近 0** | 未接触时压力读数应在 0 附近，便于判读 |
| 2 | **每次开始采集时校零一次** | 采集系统启动即执行，不需人工干预 |
| 3 | **原始数据保留、可回溯** | 要求能用连续多日（如 5 天）的数据观察零点漂移 |

---

## 二、设计原则

模块围绕三条原则实现，**所有设计取舍均由此推导**：

### 原则 1：原始值永不修改

`frame.pressure` 始终是固件原始值。校零只是**视图变换**，任何时刻都能取回原值：

```python
shown = tared.apply_frame(frame)   # 校零后（0 附近）
raw   = frame.pressure             # 原始值，一直都在
raw2  = TareFilter.raw(frame)      # 同一份数据
back  = restore(shown, offsets)    # 从校零值反算回原始值
```

### 原则 2：每次校零都留档

每次校零追加一行到 `~/.tactile500/tare/journal.jsonl`，记录：

- 时间戳（UTC）
- 每通道偏移值与极差
- 每通道状态
- 板 identity（`0x08` / `0x09` / `0x0A` / `0x0B`）
- 警告清单

**按 identity 索引而非 USB 路径，换 USB 口不失效。** 由此可事后统计零点随时间的漂移。

### 原则 3：坏通道不静默处理

饱和或无数值的通道**给 0 偏移并明确标记**，不给予一个假零点把故障掩盖过去。

---

## 三、关键技术决策

| 决策 | 选择 | 理由 |
|---|---|---|
| 校零层次 | **上位机软件**（不动固件/芯片） | 零风险、可回退、随时可改；芯片标定系数在 EEPROM，本模块完全不碰 |
| 偏移估计量 | **中位数** | 本系统存在满量程尖峰（如某通道跳至 ±943718），均值会被单个尖峰拉偏数百单位 |
| 稳定性评估样本 | **仅用 `fresh_mask` 命中帧** | 500 Hz 帧率下单次转换约 250 Hz，非 fresh 帧是重复值，用于计算极差会**低估**真实波动 |
| 校零方式 | **一次性**，不做滑动基线 | 滑动基线会把缓慢变化的**真实力**当成漂移减掉，在动态夹爪上很危险 |
| 通道状态 | 四档：`ok` / `unstable` / `saturated` / `no_data` | 使调用方可分别处理，而非笼统成败 |

---

## 四、接口

### 4.1 命名（统一 `tare` 前缀，搜索即可找齐全套）

| 名称 | 类型 | 作用 |
|---|---|---|
| `tare_now()` | 函数 | **唯一入口**：采一次零点 |
| `TareResult` | 类 | 一次校零的完整结果 |
| `TareFilter` | 类 | 把零点应用到实时帧 |
| `TareJournal` | 类 | 追加式档案 |
| `ChannelBaseline` | 类 | 单通道基线统计 |
| `restore()` | 函数 | 还原成原始值 |

### 4.2 集成方式（三步）

```python
from tactile500 import TactileSystem
from tactile500.tare import tare_now, TareFilter, TareJournal

system = TactileSystem()
native = system.subscribe(capacity=16384)
system.open()

# ① 采集系统启动时：夹爪张开、无接触，采 2 秒基线
result = tare_now(system, seconds=2.0)
for w in result.warnings:
    print("校零警告:", w)

# ② 留档（可回溯、可看长期漂移）
TareJournal().append(result, note="第 1 天开机")

# ③ 之后所有输出取自校零后的值
tared = TareFilter(result)
while True:
    item = native.get(timeout=1.0)
    shown = tared.apply_frame(item.frame)   # 0 附近
    raw   = item.frame.pressure             # 原始值，一直都在
```

### 4.3 主要参数

`tare_now(system, *, seconds=2.0, roles=None, fresh_only=True, min_samples=50, max_spread=20000, reject_saturated=True)`

| 参数 | 默认 | 说明 |
|---|---|---|
| `seconds` | 2.0 | 基线时长，建议 1~3 秒 |
| `roles` | `None` | 只校指定角色；`None` = 全部在线板 |
| `fresh_only` | `True` | 稳定性评估只用 fresh 帧 |
| `min_samples` | 50 | 少于该帧数判为 `no_data` |
| `max_spread` | 20000 | 极差超此值判为 `unstable` |

**该函数自开订阅、采完即关，不影响调用方自身的订阅。**

### 4.4 命令行工具

```bash
python tools/tare_journal.py show                     # 列出全部校零记录
python tools/tare_journal.py drift 0x0A               # 每通道漂移（末次 − 首次）
python tools/tare_journal.py drift 0x0A --channel 1   # 单通道逐次漂移
python tools/tare_journal.py latest 0x0A --out t.json # 导出最新一次
python tools/tare_journal.py restore raw.csv t.json   # CSV 还原为原始值
```

---

## 五、实机验证

**平台**：AgiBot G2（Ubuntu 22.04 / aarch64 / 5.10.220-rt112 实时内核）
**配置**：四板共 88 通道，各 500 Hz 接收
**版本**：tactile500 0.4.1（安装后复验）

### 5.1 基线采集结果

| 角色 | 通道 | ok | 不稳 | 饱和 | 无数据 |
|---|---:|---:|---:|---:|---:|
| right_palm | 32 | 32 | 0 | 0 | 0 |
| left_palm | 32 | 32 | 0 | 0 | 0 |
| right_fingers | 12 | 12 | 0 | 0 | 0 |
| left_fingers | 12 | 11 | 0 | **1** | 0 |
| **合计** | **88** | **87** | 0 | **1** | 0 |

**唯一异常**：`left_fingers` ch0 顶到满量程（±943718，即 24 位 ADC 到达端点）。
模块**已按设计跳过并告警**，未给予假零点：

```
⚠ left_fingers ch0 顶到满量程，已跳过（硬件/接线问题）
```

该通道为硬件/接线问题，**非软件缺陷**（芯片自身的错误码 `Negative signal out of range` 亦对应此现象）。

### 5.2 校零效果

| 角色 | 校零后前 3 通道 | 校零后绝对值最大 | 满量程 |
|---|---|---:|---:|
| left_palm | 16, 10, 11 | **66** | 943718 |
| right_palm | -20, -3, -34 | **55** | 943718 |
| right_fingers | 210, -141, 90 | **379** | 943718 |
| left_fingers | (-943718 饱和), 194, 5 | 见备注 | 943718 |

**残差为满量程的 0.006% ~ 0.04%**，满足"输出值接近 0"的要求。

> 备注：`left_fingers` ch0 因饱和未校零，读数保持原始饱和值——这是**有意为之**，
> 避免把硬件故障伪装成"已修复"。

### 5.3 可回溯性验证

| 验证项 | 结果 |
|---|---|
| `restore(shown, offsets) == raw` | **四板全部一致** ✓ |
| `frame.pressure` 是否被修改 | **未被修改** ✓ |
| 档案写入 | `~/.tactile500/tare/journal.jsonl` ✓ |

### 5.4 自动化测试

- 校零专项测试：**12 项**（含饱和/不稳/无数据判定、档案与漂移、还原回路、别名兼容）
- 全套测试：**24 项全部通过**
- 覆盖场景：端到端基线测量、原始值不变性、fresh 样本选择、档案损坏行容错、JSON 往返

---

## 六、已知边界

| # | 边界 | 说明 |
|---|---|---|
| 1 | **单位仍为"固件值"** | 本模块输出**相对变化量**；绝对值量纲（Pa / N）需另行实物标定 |
| 2 | **需人工保证空载** | 校零时夹爪必须张开且无接触；模块仅能通过数值稳定性兜底提示 |
| 3 | **一次性校零** | 不自动跟随温漂；需要时再次调用 `tare_now()` |
| 4 | **不替代芯片标定** | 芯片标定系数存于 NSA2302 的 EEPROM（`0xAE`~`0xBC`），本模块完全不读写 |
| 5 | **饱和通道无法修复** | 硬件问题；模块的职责是**如实报告**而非掩盖 |

---

## 七、交付物

| 文件 | 位置 | 行数 |
|---|---|---:|
| 校零核心模块 | `upper_pyusb_500hz/src/tactile500/tare.py` | 362 |
| 单元测试 | `upper_pyusb_500hz/tests/test_tare.py` | 182 |
| 命令行工具 | `upper_pyusb_500hz/tools/tare_journal.py` | 162 |
| 模块文档 | `upper_pyusb_500hz/docs/TARE.md` | 175 |

### 安装包

| 文件 | 大小 | SHA-256 |
|---|---:|---|
| `tactile500-0.4.1-py3-none-any.whl` | 43,803 B | `94EB9969A7AEEA1C22A8AF9ABEB92C0C94B830E8F82A7F516235CF22DA13A0C2` |
| `tactile500-0.4.0-py3-none-any.whl` | 43,558 B | `F865FA13DE5BBC31023C0335B75AD23BF01C022DB97E252D88572A67D0B9E525` |
| `tactile500-0.3.0-py3-none-any.whl` | 38,152 B | `91C3FFF10F87303007847D0737833BD6A8B09C4B6C0409A24B038F63D1F4A0C9` |

> **0.3.0 为不含校零的原始交付件**，已校验为原件（构建过程曾一度覆盖，已从版本历史还原并核验哈希）。

安装：

```bash
pip install --no-index --find-links wheelhouse tactile500==0.4.1
```

---

## 八、版本沿革

| 版本 | 变更 |
|---|---|
| **0.4.1** | 主函数改名 `measure_baseline` → **`tare_now`**，统一 `tare_*` 前缀；旧名保留为别名 |
| 0.4.0 | 新增软件校零模块（`tare.py` / CLI / 文档 / 测试） |
| 0.3.0 | 原始交付（无校零功能） |

**兼容性**：`measure_baseline` 仍指向 `tare_now`，0.4.0 的调用方无需改动。

---

## 九、后续建议

| 议题 | 说明 |
|---|---|
| **漂移告警阈值** | 当前只记录不告警。建议积累数日 journal 数据后，依据实测漂移分布确定阈值 |
| **网页端统一** | R14 网页上位机的 `/api/tare` 目前为独立实现，建议改用本模块以获得同样的饱和检测与质量评估 |
| **`left_fingers` ch0 硬件排查** | 该通道持续负满量程，建议检查接线与传感器本体 |

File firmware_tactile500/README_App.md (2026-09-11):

# Tactile500 固件（APM32F402RB）

**最新调整（2026-09-10，OSR256试验）：压力/温度OSR均已改为256（A6=0x40、A7=0x80），六板型已重新编译，等待用户烧录后测量。当前烧录文件与步骤见[OSR256入口](烧录_OSR256_20260910/先读我_OSR256烧录.md)。以下早先实测记录对应OSR2048，不能作为256档实测结果。**

本目录是触觉板固件的唯一应用入口。目标：由 MCU 硬件定时器原生按 2 ms 周期发送；每帧携带左/右、12/32 通道、32 通道长/短线、映射版本、固件修订、序号、采集时间和有效性信息。

**本轮用户确认：左12、左32、右12、右32四板经同一Hub接入；先烧录32点短线新版。
第一阶段验收每板500完整帧/秒，ADC新转换率另测。** 短线=新版（原NEW_HARDWARE=1），
长线=旧版（=0）。先看[首次烧录说明](先读我_四板首次烧录.md)与[板型和用户实测位置表](docs/BOARD_VARIANTS_AND_CHANNEL_MAP.md)。

**交付状态（2026-09-10）：当前固件修订 0x21，六种板型已用 Arm GNU Toolchain 重建。用户通过 Keil 重建并烧录左12和左32短线；G1 已收到两板原生约500帧/秒及温度/压力数值。首次实物反馈后的 DMA 修正见 [修订21说明](docs/REVISION_21_HARDWARE_FIX.md)。当前 DRDY 全0，仍未证明每通道500Hz新ADC转换，也未做示波器时序验证。**

## 入口与板型

- Keil 工程：[Project/MDK/Tactile500.uvprojx](Project/MDK/Tactile500.uvprojx)
- 已构建固件：[build/gcc](烧录_OSR256_20260910)，选择与实际板子一致的目录，不要把六份依次烧到同一块板。
- 固件参数：[Include/tactile_config.h](Include/tactile_config.h)
- 协议及上位机对接：[docs/PROTOCOL_V2.md](docs/PROTOCOL_V2.md)
- 改动、DMA 配置、烧录与验收：[docs/CHANGELOG_AND_BENCH_PLAN.md](docs/CHANGELOG_AND_BENCH_PLAN.md)

| 板型 | Keil Target 后缀 | GNU 固件目录 | 身份字节 |
|---|---|---|---|
| 左手 12 点 | Left_Fingers12 | left_fingers12 | 0x08 |
| 右手 12 点 | Right_Fingers12 | right_fingers12 | 0x09 |
| 左手 32 点长线 | Left_Palm32_Long | left_palm32_long | 0x0A |
| 右手 32 点长线 | Right_Palm32_Long | right_palm32_long | 0x0B |
| 左手 32 点短线 | Left_Palm32_Short | left_palm32_short | 0x0E |
| 右手 32 点短线 | Right_Palm32_Short | right_palm32_short | 0x0F |

所有 Keil Target 均以 `Tactile500_` 开头。默认选择右手 32 点短线，与原工程宏设置对应。左右和线缆身份由烧录的 Target 决定，不是自动识别接线；烧错固件会报告错误身份。同型多块板目前用 USB 设备路径区分，协议未加入唯一芯片序列号。

## 构建及离线验证

从本目录执行，Python 需要 3.10 或更高版本：

```powershell
python tools/build_firmware.py --profile all
# 如编译器不在 PATH，可指定：
python tools/build_firmware.py --profile right_palm32_short --cc C:/Toolchains/bin/arm-none-eabi-gcc.exe
# Windows 已装 MSVC 时，一次运行 C 测试及独立解码测试：
powershell -ExecutionPolicy Bypass -File tools/test_core.ps1 -Python python
# 检查上位机保存的原始 UART 字节，不是 CSV 或旧版 BT 帧：
python tools/protocol_v2.py capture.bin --output capture_report.json
```

GNU 构建工具自动复制所需源文件到临时目录，适配当前中文路径；输出到 `build/gcc/<profile>/`。构建清单包含源码和固件 SHA-256，见 `build/gcc/build_manifest.json`。该工具只编译，不操作烧录器。

本轮已在本机用Keil 5.27.1 + Arm Compiler 5.06 update 6 (build 750) 与
Geehy.APM32F4xx_DFP.1.0.7支持包重建全部六个Target：均为0错误、27条相同的C4008W编译选项提示。
GNU 14.3.Rel1也已重建六种固件。两套共12份HEX的校验、Flash范围和启动/中断向量检查通过，
SHA-256与检查记录见[本轮构建清单](烧录_OSR256_20260910/先读我_OSR256烧录.md)。本轮未烧录硬件。

## 源文件职责

| 文件 | 职责 |
|---|---|
| Source/main.c | 主循环采集组帧、定时发送、异常恢复 |
| Source/tactile_time.c | DWT 微秒时基、TMR2 500 Hz 触发 |
| Source/tactile_stream.c | 两个帧缓冲区的归属、丢帧和恢复 |
| Source/tactile_protocol.c | 帧编码、CRC-16 |
| Source/tactile_sensor.c | NSA2302 初始化、限时 SPI 读取和新数据标记 |
| Source/tactile_channels.c | 12 点与 32 点长/短线片选顺序 |
| Config/Source/apm32f4xx_*_cfg.c | 芯片时钟、GPIO、SPI、USART2、NVIC |
| tools/protocol_v2.py | 无第三方依赖的独立字节流解码与采集文件统计 |

旧版 `I2C_TwoBoardsPolling` 应用已迁移为 `Applications/Tactile500`。误导性的旧 I2C 工程、旧操作说明、备用 main、旧 EEPROM 命令路径移入上位目录的 `备份/legacy_project_files_20260910`；原应用修改前完整 ZIP 在 `备份/TactileFirmware_before_500Hz_20260910_141543.zip`。SDK 的 Libraries、Boards、Documents 保持原厂名称与内容。

V2 帧替换旧 BT 温度/压力双帧；旧上位机需要按协议适配。没有修改或提前审阅正在由 DeepSeek 编写的上位机。

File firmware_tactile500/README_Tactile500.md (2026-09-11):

# 嵌入式代码入口

当前触觉固件位于 [Tactile500 固件](README_App.md)。

本轮先看[四板首次烧录说明](先读我_四板首次烧录.md)：左12、右12、左32和右32各500帧/秒，
先测试32点短线新版。短线=新版，长线=旧版；用户实测位置表见[板型与通道映射](docs/BOARD_VARIANTS_AND_CHANNEL_MAP.md)。

请打开 [Tactile500.uvprojx](Project/MDK/Tactile500.uvprojx)，按实际左/右、12/32 点及长/短线选择 Target。六份已构建的 GNU HEX 位于 [build/gcc](烧录_OSR256_20260910)。

原 I2C_TwoBoardsPolling 示例名称已退休；旧工程和旧说明存放在嵌入式代码上一级的备份目录。Libraries、Boards、Documents 为原厂 SDK 资源，名称保持不变。

当前V2版本字节保持0x21。本轮新增板型/发包预算检查并重新构建、测试；本轮产物尚未上板测量，
传感器新数据率另行验收。历史0x21实机记录见[修订21说明](docs/REVISION_21_HARDWARE_FIX.md)。
详细变更和现场步骤见[改动与上板验收](docs/CHANGELOG_AND_BENCH_PLAN.md)。

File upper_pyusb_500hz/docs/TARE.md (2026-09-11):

# 软件校零（tare）

**把静止基线从压力值里减掉，让"未接触"时读数接近 0；同时完整保留原始值，可随时还原。**

面向调用方（你的采集系统插件）：在每次开始采集前调用一次 `tare_now()`，
之后用 `TareFilter` 处理订阅到的帧即可。

---

## 命名（搜 `tare` 即可找齐全套）

| 名称 | 类型 | 作用 |
|---|---|---|
| **`tare_now()`** | 函数 | **唯一入口**：采一次零点 |
| `TareResult` | 类 | 一次校零的完整结果（偏移 + 质量 + 警告） |
| `TareFilter` | 类 | 把零点应用到实时帧 |
| `TareJournal` | 类 | 追加式档案，用于回溯与漂移分析 |
| `ChannelBaseline` | 类 | 单通道基线统计 |
| `restore()` | 函数 | 把校零值还原成原始值 |
| `tactile500.tare` | 模块 | |
| `docs/TARE.md` | 文档 | 本文件 |
| `tools/tare_journal.py` | CLI | 漂移分析 / 还原 |
| `~/.tactile500/tare/journal.jsonl` | 档案 | 每次校零追加一行 |

> `measure_baseline` 是 0.4.0 的旧名，保留为 `tare_now` 的别名，可继续使用。

---

## 三条铁律

| # | 规则 | 为什么 |
|---|---|---|
| 1 | **原始值永不修改** | `frame.pressure` 始终是固件原值；校零只是"视图" |
| 2 | **每次校零都留档** | 追加式 JSONL，可事后统计多天的零点漂移 |
| 3 | **坏通道不静默处理** | 饱和/无数据的通道给 0 偏移并标记，不假装修好了 |

---

## 快速开始

```python
from tactile500 import TactileSystem
from tactile500.tare import tare_now, TareFilter, TareJournal

system = TactileSystem()
native = system.subscribe(capacity=16384)
system.open()

# ① 采集系统启动时：夹爪张开、无接触，采 2 秒基线
result = tare_now(system, seconds=2.0)
for w in result.warnings:
    print("校零警告:", w)

# ② 留档（可回溯、可看长期漂移）
TareJournal().append(result, note="第 1 天开机")

# ③ 之后所有输出都从校零后的值取
tared = TareFilter(result)
while True:
    item = native.get(timeout=1.0)
    frame = item.frame
    shown = tared.apply_frame(frame)   # 0 附近
    raw = frame.pressure               # 原始值，一直都在
```

---

## API

### `tare_now(system, *, seconds=2.0, roles=None, fresh_only=True, min_samples=50, max_spread=20000, reject_saturated=True, capacity=8192, max_frames=40000) -> TareResult`

采集静止基线。**调用方必须保证夹爪空载**——本函数只能靠"数值是否稳定"兜底提示。

| 参数 | 说明 |
|---|---|
| `seconds` | 基线时长，建议 1~3 秒 |
| `roles` | 只校这些角色（`left_palm` / `left_fingers` / `right_palm` / `right_fingers`）；`None` = 全部 |
| `fresh_only` | **稳定性评估只用 `fresh_mask` 命中的帧**（那些才是真新转换） |
| `min_samples` | 少于该帧数判为 `no_data` |
| `max_spread` | 极差超过它判为 `unstable` |
| `reject_saturated` | 是否拒绝顶到满量程的通道 |

它自己开一个订阅、采完就关，**不影响你自己的订阅**。

### `TareResult`

```python
result.offsets          # {role: (每通道偏移,)}
result.baselines        # {role: (ChannelBaseline,)}  含 offset/spread/samples/status
result.identities       # {role: identity 整数}
result.warnings         # 人类可读的警告
result.created_iso      # ISO 时间戳
result.to_json()        # 可序列化，供持久化
TareResult.from_json(d)
```

### `TareFilter(result, *, strict=False)`

```python
f.apply(role, pressure)      # 按角色校零
f.apply_frame(frame)         # 便捷入口
f.offsets_for(role)
TareFilter.raw(frame)        # 永远能拿回原始值
restore(tared, offsets)      # 把校零值还原成原始值
```

---

## 通道状态判定

| status | 条件 | 偏移取值 | 含义 |
|---|---|---|---|
| `ok` | 样本够、极差 ≤ `max_spread` | 中位数 | 正常 |
| `unstable` | 极差 > `max_spread` | 中位数 | **夹爪可能没空载**，或通道噪声大 |
| `saturated` | 中位数或极值顶到 ±943718 | **0** | 24 位 ADC 到端点，硬件/接线问题 |
| `no_data` | 样本不足，或全是哨兵 −8388608 | **0** | 设备没在线或通道未就绪 |

**为什么用中位数而不是均值**：本系统存在满量程尖峰（如左手 12 点 ch0 会跳到 −943718），
均值会被单个尖峰拉偏几百个单位，中位数不受影响。

**为什么稳定性用 fresh 帧算**：500 Hz 帧率下单次转换约 250 Hz，非 fresh 帧是重复值，
用它们算极差会低估真实波动。

---

## 档案与漂移回溯

每次校零追加一行到 `~/.tactile500/tare/journal.jsonl`：

```python
journal = TareJournal()            # 或 TareJournal(自定义路径)
journal.append(result, note="第 3 天开机")
journal.history(identity="0x0A")   # 按时间顺序
journal.latest(identity="0x0A")
journal.drift(identity="0x0A")     # 某块板的零点随时间变化
```

命令行工具（pip 装完即用，不必进源码目录，入口在 `pyproject.toml` 的 `[project.scripts]`）：

```bash
tare --seconds 2 --note "第 1 天开机"     # 采一次零点：打印 JSON 并写入档案
tare -s 2 --roles left_palm right_palm    # 只校两块掌板
tare --no-journal --out tare.json         # 只测不存档，另存一份 JSON 给采集脚本
tare --simulate -s 1                      # 无实物自检（四板模拟源，不碰 USB）
tare --help
```

退出码：`0` 成功；`1` 一块板都没采到（设备不在线）；`130` 被 Ctrl+C 打断。
`--simulate` 走 `simulation.demo_system()`，模拟源本身是正弦信号，所以一定会出现
"基线不稳"告警——它只用来验证命令链路，不能当校零效果证据。

源码树里没装 wheel 时，等价写法是 `python -m tactile500.tare --simulate -s 1`。

档案查询与还原（这两个是仓库脚本，需在项目根目录执行）：

```bash
python tools/tare_journal.py show                     # 列出全部记录
python tools/tare_journal.py drift 0x0A               # 每通道漂移（末次 − 首次）
python tools/tare_journal.py drift 0x0A --channel 1   # 单通道逐次漂移
python tools/tare_journal.py latest 0x0A --out t.json # 导出最新一次
python tools/tare_journal.py restore raw_left_big.csv t.json   # CSV 还原成原始值
```

按 **identity**（`0x08`/`0x09`/`0x0A`/`0x0B`）索引而非 USB 路径，**换 USB 口不失效**。

---

## 实测（2026-09-11，G2，四板）

```
right_fingers  12通道  ok=12  饱和=0
right_palm     32通道  ok=32  饱和=0
left_palm      32通道  ok=32  饱和=0
left_fingers   12通道  ok=11  饱和=1
⚠ left_fingers ch0 顶到满量程，已跳过（硬件/接线问题）

校零后残差：left_palm 最大 39 / right_palm 51 / right_fingers 404
还原验证：四板全部一致
原始值：frame.pressure 未被修改
```

---

## 边界与注意事项

1. **单位仍是"固件值"**，不是 Pa 也不是 N。校零后是**相对变化量**；绝对量纲需实物标定。
2. **一次性校零**，不做滑动基线。滑动基线会把缓慢变化的真实力当成漂移减掉——
   动态夹爪上很危险。需要重校时再调一次 `tare_now()`。
3. **温漂**：芯片 DSP 已做二阶温度补偿，残余漂移较小；长期漂移可由 journal 的 drift 曲线观察。
4. **不要用它代替芯片标定**。芯片标定系数在 EEPROM（`0xAE`~`0xBC`），本模块完全不碰。
5. 饱和通道（如 `left_fingers ch0`）**修不好就是修不好**——本模块只负责不让你误以为是零点。

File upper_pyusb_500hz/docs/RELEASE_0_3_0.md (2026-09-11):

# 0.3.0 今晚测试交付

日期：2026-09-10。固件保持已构建的V2修订0x21；Python包为tactile500 0.3.0。
一个wheel包含采集API与可选查看界面。不运行view时，核心不加载网页服务。
Windows浏览器只访问G1上的查看服务；USB接收、解码和原始数据文件均在G1。

## 已准备的入口

- [安装包](../wheelhouse/tactile500-0.3.0-py3-none-any.whl)
- [离线依赖PyUSB 1.3.1](../wheelhouse/pyusb-1.3.1-py3-none-any.whl)
- [固件Keil工程](../../firmware_tactile500/Project/MDK/Tactile500.uvprojx)
- [按四块实物选择HEX](../../firmware_tactile500/先读我_四板首次烧录.md)
- [MCU完整通信协议](../../firmware_tactile500/docs/PROTOCOL_V2.md)

G1已经建立独立环境：`/home/agi/tactile500_release_20260910_03/.venv`。
此前0.2.0实验目录与机器人应用环境保留。SSH 地址形如
`agi@<G1-IP>`（把 `<G1-IP>` 换成机器人当前实际地址）；换网络后需重新确认。

在G1终端中执行：

```bash
cd /home/agi/tactile500_release_20260910_03
.venv/bin/tactile500 scan
.venv/bin/tactile500 view --bind 0.0.0.0 --port 8875 --output-root captures
```

Windows浏览器打开 `http://<G1-IP>:8875`。板卡烧录后上电自动输出，主机无需发送启动命令。
软件以线上身份选择左12、右12、左32、右32；右侧实物尚未接上时显示未检测到。
界面有全部88个通道的压力变化量和温度、选中通道趋势、收包率、数据年龄、缺口和坏帧。
点击通道可在详情中核对显示位置与MCU通道。短线新版使用用户确认的32点位置表；
长线或未知映射保留原始通道并明确提示位置未确认。

点击“开始原始录制”后，G1的captures下创建唯一目录，包含各设备的t5raw与session.json。
点击“停止并保存”只停止此次录制，采集和显示继续；Ctrl+C结束整个服务并保存余下记录。
在G1可用以下命令重新逐帧验证CRC、帧数和缺口：

```bash
.venv/bin/tactile500 inspect captures/<界面显示的目录名>
```

G1日历时间目前与Windows不同；目录名沿用G1本地时间并带随机后缀，
测试报告另用Windows日期标识。速率与数据年龄采用单调时钟，不依赖日历时间。

## 接入Python系统

```python
from tactile500 import TactileSystem

system = TactileSystem()
frames = system.subscribe(capacity=8192)
system.open()
try:
    while True:
        item = frames.get(timeout=1)
        f = item.frame
        # 原始通道顺序；每块实物每个完整帧单独交付。
        consume(f.role, f.sequence, f.temperature, f.pressure, f.fresh_mask)
finally:
    system.close()
    frames.close()
```

如需在已有TactileSystem上增加查看，可复用同一对象创建
`Monitor(system, Path("captures"))`，并用`make_server`启动HTTP；
不要同时启动另一份独立view/capture进程抢占同一CH340。
原始Python接口和录制没有按10Hz降采样。500Hz快照不是同步ADC采样保证，
接口详细说明见[API文档](API_AND_INTEGRATION.md)。

## 显示与采集速率

- 原始USB层持续异步读取，独立解码；原始录制采用有界队列与独立写盘线程。
- 查看服务每100ms生成一次JSON缓存，HTTP请求只读缓存，不向采集层新增订阅。
- 浏览器约10Hz更新，曲线保留20秒抽样趋势，不能用于读取2ms级瞬态峰值；分析用t5raw。
- 主机收包率为近期约1秒统计；详情另有全程主机平均值和MCU时间戳推算值。
- 累计序号缺口、稳态坏帧、重复、USB输入队列丢块和录制丢弃分别显示/记录。
- 断线、数据过期、身份冲突会明确显示，不把无数据的板子画成正常运行。
- 压力尚未标定为N或Pa，界面基线只改变显示，不改传输值或文件。
- fresh=0的现有行为保持；不能把完整帧500Hz说成每通道500次新ADC转换。

四板UART有效负载理论总和是260,000字节/秒，原始录制每帧另加24字节主机元数据，
四板约308,000字节/秒，约1.11GB/小时（十进制，另有少量头部）。
G1空间有限，长时间录制前检查目标盘容量。HTTP流量另行实测列在性能报告中。

## 今晚烧录后的检查

1. 四块板分别选择正确Target：左12=08、右12=09、左32短=0E、右32短=0F。
2. 烧录Verify后正常运行、接入Hub；先枚举再查看身份和数据。
3. 四角色在线后录制至少60秒，核对约500帧/秒、序号缺口0、稳态坏帧0和录制丢弃0。
4. 逐点按压核对32点映射；特别检查左12原始ch12此前恒定471797是否响应。
5. 实物四板稳定后，再安排长时间测试及ADC新转换率测量。

查看服务默认仅监听127.0.0.1；上述0.0.0.0命令用于本次可信实验局域网。
它没有用户登录功能，不用于公网部署。录制控制有同源与随机请求令牌检查。
默认使用8875端口，避开G1已经占用的8765。Windows直接USB采集未列入本次实机验收范围。

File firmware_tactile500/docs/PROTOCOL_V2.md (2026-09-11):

# Tactile500 V2 串口协议

版本日期：2026-09-10。传输为 USART2（PA2）TX、921600、8 数据位、无校验、1 停止位；每块板 500 个发送时隙/秒。所有多字节数值均为小端。一个帧同时承载全部温度和压力。

**与旧 BT 温度/压力双帧不兼容。** 接收端必须先做同步、长度/身份校验及 CRC 验证，再解释字段；USB 一次读取可以包含半帧、多帧或帧尾+帧头。

## 帧布局

N 为 12 或 32。总字节数 L = 20 + 5N，即 80 或 180。

| 偏移（从 0 开始） | 字节数 | 字段 | 定义 |
|---|---:|---|---|
| 0 | 2 | sync | A5 5A |
| 2 | 1 | frame_length | 含帧头及 CRC 的总长度 |
| 3 | 1 | wire_version | 高 4 位协议主版本，低 4 位固件修订；当前 0x21 |
| 4 | 1 | identity | 左右、数量、长短线、映射版本 |
| 5 | 1 | status | 本帧状态及启动以来锁存的异常 |
| 6 | 4 | sequence | uint32，发送时隙序号，从 1 开始 |
| 10 | 4 | sample_time_us | uint32，本次遍历传感器开始时刻，单位 us |
| 14 | 4 | fresh_mask | uint32，第 i 位对应数组索引 i 的通道 |
| 18 | 2N | temperature[N] | int16 小端，沿用旧固件标度 0.1°C/计数 |
| 18+2N | 3N | pressure[N] | int24 小端，有符号二进制补码 |
| 18+5N | 2 | crc16 | 前 L-2 字节的 CRC，低字节先发 |

32 点温度从偏移 18 开始，压力从 82 开始，CRC 在 178、179；12 点压力从 42 开始，CRC 在 78、79。

压力数值为传感器 signed24 原始压力结果乘 9 再除 80，整数向零截断，等价于沿用原来的 0.1125 比例。浮点改整数可能与旧结果存在极小的末位舍入差异。**该量不能未经标定直接命名为 N 或 kPa。** 温度保留旧公式 signed16 × 10 / 256，并修正了负数解码；实际温度标度还应与现场标定交叉验证。

尚无可读测量时，温度为 -32768，压力为 -8388608。修订 0x21 即使 DRDY=0 也读取数据寄存器；fresh=0 可能是未获得新转换证据的当前寄存器值、失败时的缓存或启动哨兵。不能只看数值变化与否判断新旧。实机连续 DAC 模式下 DRDY 始终为0，但能读取变化数值；不要将该位全0直接解读为所有传感器断线。

## 身份字段

| 位 | 含义 |
|---|---|
| bit0 | 0=左手，1=右手 |
| bit1 | 0=12 通道，1=32 通道 |
| bit2 | 32 通道时 0=长线旧版，1=短线新版（与旧NEW_HARDWARE语义一致）；12 通道时必须为 0，并解码成 none |
| bit7:3 | 映射版本；当前为 1 |

对应身份：左12=08，右12=09，左32长=0A，右32长=0B，左32短=0E，右32短=0F（十六进制）。

协议版本和映射版本是两个不同维度。未知主协议版本不可按 V2 解析；未知映射版本允许保存数值，但应标记“未知通道映射”，不能默认为当前手掌位置。固件修订号仅有 4 位，构建追溯以 build_manifest.json 中的哈希为准。

身份来自编译板型，没有自动探测左右或线缆；当前也没有 MCU 唯一 ID。相同身份的两块实物须按 USB 设备路径分别处理、保存文件。

## 状态和新数据

| status 位 | 掩码 | 含义 |
|---|---|---|
| bit0 | 0x01 | 本帧至少一个通道不是有效新数据 |
| bit1 | 0x02 | 本次采集出现 SPI 超时或硬件错误 |
| bit2 | 0x04 | 本次采集读到 NSA2302 传感器错误位 |
| bit3 | 0x08 | 启动初始化中有通道失败；该失败掩码保留到重启 |
| bit4 | 0x10 | 启动以来出现采集预算耗尽、帧未按时备好或晚完成丢弃 |
| bit5 | 0x20 | 启动以来某次发送时隙到达时 UART/DMA 仍忙 |
| bit6 | 0x40 | 启动以来出现 DMA/UART 启动或传输错误 |
| bit7 | 0x80 | 启动以来出现错过定时周期或超出启动迟到限制 |

bit4..7 为锁存位，后续帧持续报告，重启清除；计数详情可在调试器查看 `g_tactile_stream`。低位报告本次采集情况，其中初始化失败不会自动消失。异常可能在已组好的帧之后发生，因此最迟通过后续组帧反映，不能只依赖单帧 status 判断链路完整性；序号缺口是另一条证据。

fresh_mask 第 i 位为 1 的条件：该通道初始化未失败、读取前 DRDY=1、传感器 ERROR_CODE=0，并且读取测量值的 SPI 事务成功。12 通道仅低 12 位有效。全新掩码分别为 00000FFF、FFFFFFFF。

DRDY 说明见随交付的 NSA2302 数据手册第 9 页（文件名 Rev1.2，页眉印为 Datasheet (EN) 0.3）：新数据产生后置位，读数据后清除。它证明本次读到了芯片报告的新数据，不代表各通道同步采样，也不能证明所有压力/温度转换都达到 500 次/秒；跨 SPI 读取的一致性仍需实际波形验证。

## 时间、序号与缓冲

时隙序号每 2 ms 增加，不因少发而暂停。错过的帧不补发，接收端通过 `(new-old) & 0xFFFFFFFF` 的增量统计缺口。相同序号为重复包；异常大的倒退应按重启或乱序处理，不能累加成数十亿丢包。

timestamp 是 MCU 启动后微秒时基的低 32 位，约 71 分 34.97 秒回绕。它记录一轮采集的开始，不是 USB 收到的时间，也不是 32 个传感器的共同转换时刻。主循环在前一帧发送期间准备下一帧，所以采集时间通常早于本帧发送时隙。

USB 主机调度会把多个串口帧合并到一次读取。应持续读取并逐帧解码，不要按 500 Hz sleep 读取、强行重采样或把一次 USB 读取当一帧。端到端帧率应同时记录 PC 单调时钟的收包区间；MCU timestamp 只能用于核对 MCU 内部节拍，不能单独证明晶振实际频率正确。

## CRC 与参考实现

CRC-16/CCITT-FALSE：poly=0x1021，init=0xFFFF，refin=false，refout=false，xorout=0。覆盖从 A5 5A 到最后一个压力字节，包含帧长度等头部字段。标准检查串 `123456789` 的结果为 0x29B1。

独立 Python 实现：

```python
from binascii import crc_hqx
expected_crc = crc_hqx(packet[:-2], 0xFFFF)
assert int.from_bytes(packet[-2:], "little") == expected_crc
```

完整可复用的 `Frame`、`decode_frame`、`StreamDecoder.feed` 在 [../tools/protocol_v2.py](../tools/protocol_v2.py)。该文件使用标准库，可直接交给上位机作者对接；不承担 CH340 驱动安装、USB 控制请求或 GUI。

离线输入必须是桥接芯片还原后的原始 UART 字节流。不要未经确认把其他 USB 桥的包头规则套到 CH340；具体 USB 传输层按实际 VID/PID 和端点验证。多设备每个设备分别保存文件。

## 映射版本 1

数组顺序沿用旧固件，不在上位机再次套用相同排列。

- 12 点：PC0..PC11；数组前 6 个走 SPI1，后 6 个走 SPI2。
- 32 点短线：CS1..CS32；前 16 个走 SPI1，后 16 个走 SPI2。
- 32 点长线：下表逻辑序号与物理 CS，前 16 个走 SPI1，后 16 个走 SPI2。

```text
逻辑  1..16 -> CS 16,13,12,11,10,9,8,7,1,2,3,4,5,6,14,15
逻辑 17..32 -> CS 26,25,24,23,32,31,30,29,28,27,17,18,19,20,21,22
```

| CS | GPIO | CS | GPIO | CS | GPIO | CS | GPIO |
|---:|---|---:|---|---:|---|---:|---|
| 1 | PB5 | 9 | PB8 | 17 | PA9 | 25 | PC5 |
| 2 | PB4 | 10 | PB9 | 18 | PA8 | 26 | PC4 |
| 3 | PB3 | 11 | PC0 | 19 | PC9 | 27 | PA10 |
| 4 | PD2 | 12 | PC1 | 20 | PC8 | 28 | PA11 |
| 5 | PC12 | 13 | PC2 | 21 | PC7 | 29 | PA12 |
| 6 | PC11 | 14 | PA15 | 22 | PC6 | 30 | PB11 |
| 7 | PB6 | 15 | PC10 | 23 | PB1 | 31 | PB10 |
| 8 | PB7 | 16 | PC3 | 24 | PB0 | 32 | PB2 |

以上是逻辑/片选映射，不代替实际触点位置图。首次验收仍须逐点按压核对左右和空间位置。

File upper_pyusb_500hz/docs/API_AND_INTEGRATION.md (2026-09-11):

# V2 API 与大系统集成

## 对象和职责

`TactileSystem(expected_roles=ROLES, scan_interval=0.5, stale_seconds=0.020,
no_data_seconds=2.0, usb_io="async")` 管理采集。构造不打开 USB；`open()` 启动后可先没有
任何板，随后插入自动发现。`close(timeout=8.0)` 停止读取并等待处理线程结束；同一对象
关闭后不能再次打开，需创建新对象。不要把 `system.status()` 当作实时流反复高频轮询。

`subscribe(capacity=8192)` 返回独立有界订阅。`get(timeout=...)` 没有数据时抛出标准
`queue.Empty`。消费者慢时丢弃其最旧数据，`subscription.dropped` 累计，其他订阅不受影响。
用户回调、机械臂控制和磁盘写入应在消费线程执行。`Recorder` 自带独立消费线程和 32768
帧队列，先关闭 system 再关闭 recorder 可以将剩余队列写完。

`ReceivedFrame` 不可变字段：

| 字段 | 意义 |
|---|---|
| frame | CRC 验证后的 `Frame` |
| path | 当前 USB 拓扑路径，仅作设备连接标识 |
| epoch | 该路径重连、MCU 重启或身份改变时增加的代数 |
| host_read_start_ns | 完成该帧的 USB 请求提交时刻（异步时包含在队列中等待的时间） |
| host_read_end_ns | 该请求完成回调被执行时的主机单调时刻 |
| flags | 位 0 序号缺口、位 1 重复、位 2 重置/倒序、位 3 同一次读取解析出多帧 |

主机时间戳不是 UART 硬件边沿时间。`host_read_end_ns - host_read_start_ns` 包含排队时间，
不能解释为 UART 传输耗时或传感器延迟。每板已预排队的请求按提交顺序交付；回调被主机
调度延迟时，仍保留 MCU 时间戳和序号，不伪造均匀的到达时间。

`Frame` 字段：`version`, `identity`, `status`, `sequence`, `sample_time_us`, `fresh_mask`,
`temperature`, `pressure`, `raw`。后两个数值数组是不可变 tuple；`raw` 为完整 V2 帧。
派生属性包括 `role`, `hand`, `channels`, `cable`, `mapping_revision`。

`status()` 返回每条路径的连接、身份、累计帧数、缺口、重复、重置、CRC 候选拒绝、输入队列
丢弃和各订阅丢弃。`host_received_rate_hz` 按首末帧主机时间计算，重连停顿计入平均值；
`mcu_received_rate_hz` 按同板 MCU 时间间隔计算；`mcu_scheduled_rate_hz` 还包含序号缺口。
MCU 重置后的时间间隔不跨越累加。总 `rejected_candidates` 可包括连接开始时的残片，
应结合 `startup_rejected_candidates` 与 `stream_rejected_candidates` 判断。

## 同一主机时间轴

`snapshot(target_ns=None, previous=None)` 选取每个角色在 `target_ns` 及之前最近收到的帧。
保留每路径最近 256 帧，目标早于历史缓存时返回 missing。`previous` 用于判断是否复用了
同一 `ReceivedFrame`。重复读的数值即使完全一样，也不能据此判定 ADC 没有转换。

`snapshots(hz=500, delay_seconds=0.004)` 在统一时间网格上产生 `Snapshot`，其中
`target_ns` 是目标主机时刻；`slots` 始终包含配置要求的角色。状态含义：

| 状态 | 上层处理建议 |
|---|---|
| updated | 本快照选择了新的接收帧；另看 fresh_mask 判断 ADC 新数据证据 |
| reused | 与上一快照相同的帧，不当成新的原始样本累计 |
| stale | 有历史帧，但接收年龄超过 20ms 默认阈值 |
| missing | 从未识别此角色，或目标时刻之前没有缓存帧 |
| offline | 曾识别到该角色，目前连接不可用 |
| ambiguous | 同角色存在多块在线板，不自动挑选 |

默认角色为左右各 12 路 fingers 和 32 路 palm；只用一只手时可传入
`expected_roles=("left_fingers", "left_palm")`。缺板并不妨碍其他角色出快照。

`receive_skew_ns` 是所有非 stale 的选中帧接收时刻的极差，少于两块时为 None。
同一网格解决上层时序接口的一致性；独立 MCU 的启动相位、ADC 转换相位和 USB 延迟仍存在。
没有共享触发线或 MCU 接收同步命令的实现时，软件无法证明严格同时采样。

## 故障边界和资源

每个路径持续以 0.1–2 秒退避重试，发现线程不等待单板打开成功。已知 USB 拓扑最多 64 个，
避免异常拓扑无限增生；超过时状态报告需要重启采集。输入队列每板 2048 个 USB 块，满时
丢最旧块并增加 `input_dropped_chunks`，解析器随后重新找帧头和 CRC。

异步读维护每板 32 个在途请求，典型读取长度为 12 路 64 字节 / 32 路 160 字节。
正常关闭先停止提交并等待在途请求自然完成；静默/故障才取消请求并处理取消回调，然后
释放内存和设备句柄，以保留末尾字节、减少不必要的取消。取消不能
完成时，保留仍被 C 层引用的对象并报告超时，避免释放仍在使用的缓冲区。

软件没有 Hub 供电控制，也不通过 reset_device 影响同 Hub 的其他板。总线供电 Hub
发生电气短路或上游断开时，所有板都可能掉线；程序在重新出现后按帧身份恢复。

## 物理位置与数值解释

`physical_values(frame)` 返回按物理位置排列的 `(temperature, pressure, fresh_mask)`。
32 路短线使用用户确认表；12 路维持通道 1–12 顺序；长线以及未知映射版本拒绝推断物理
布局。V2 固件已经执行片选顺序排列，不能再把同一排列应用一次。

无效哨兵为温度 `-32768`、压力 `-8388608`。传感器 fresh=0 本身不会清掉可读数值。
修订 0x21 的 DAC 连续模式实测 DRDY 全 0；当前不将这些帧宣称为每通道 500Hz 新转换。
原 OSR/滤波设置和 64 次压力后更新一次温度的工作模式也限制了实际更新率。

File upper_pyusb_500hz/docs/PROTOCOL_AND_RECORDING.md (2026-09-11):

# 线协议 V2 与录制格式 V2

所有多字节数值为小端。串口配置 921600、8 数据位、无校验、1 停止位。配套 MCU
120MHz / APB1 60MHz，实际 UART 整数分频约为 923076.9 bit/s（相对配置值 +0.16%）。

## UART 帧

| 字节偏移 | 长度 | 字段 |
|---|---:|---|
| 0 | 2 | 同步字 A5 5A |
| 2 | 1 | 总帧长 `20 + 5*N`，12 路 80，32 路 180 |
| 3 | 1 | 高 4 位协议主版本 2，低 4 位固件修订；当前 0x21 |
| 4 | 1 | identity：bit0 右1/左0；bit1 32路1/12路0；bit2 短线1/长线0；bit7:3 映射版本 |
| 5 | 1 | 状态位 |
| 6 | 4 | uint32 sequence，每个 2ms 计划槽位递增，漏发也递增 |
| 10 | 4 | uint32 sample_time_us，该帧 SPI 扫描开始时 MCU 微秒时钟 |
| 14 | 4 | uint32 fresh_mask，bit0 对应通道1 |
| 18 | 2*N | N 个 int16 温度，单位 0.1°C |
| 18+2*N | 3*N | N 个有符号 int24 压力，原有 `raw*9/80` 尺度 |
| 18+5*N | 2 | CRC-16/CCITT-FALSE，前面全部字节（含帧头）参与 |

CRC 参数：多项式 0x1021，初值 0xFFFF，RefIn/RefOut=false，XorOut=0；CRC 低字节先传。
校验向量 `123456789 → 0x29B1`。12 路 bit2 必须为 0，此时线缆解释为 none。

映射版本 1 的身份：左12=08、右12=09、左32长=0A、右32长=0B、左32短=0E、右32短=0F。
没有唯一硬件序列号。同一种身份的两块板不能仅从协议区分用途，因此实时快照报告 ambiguous。

状态字：bit0 并非所有通道 fresh；bit1 SPI 错误；bit2 传感器诊断错误；bit3 初始化读回错误；
bit4 扫描超时、bit5 TX 忙、bit6 TX 错误、bit7 定时器迟到是上电后锁存位。
fresh=1 仅表示读前 DRDY=1 且本次读成功；当前 DAC 模式的 DRDY=0 不等于数据不可读取。
温度无效值 -32768，压力无效值 -8388608，不能当有效测量值处理。

MCU 微秒时间约 71.6 分钟回绕。对差值取模 2^32；小于 2^31 的前向增量视为正常，
更大的倒向变化视为重启/乱序，不能算成几十亿个丢包。跨断线较长时间不保证回绕判别唯一，
应使用连接 epoch 和主机日志共同判断。不同 MCU 上电时间不同，其时间戳不能直接比较。

## .t5raw 文件

每条 USB 路径、连接/重启代数、身份组合写一个文件，文件名带路径和 epoch。独立于旧 T500
格式，旧解析器不能读取。文件头：8 字节 `T5V2RAW\0`，4 字节无符号小端 JSON 长度，随后
UTF-8 JSON。JSON 包含 `format_version=2`、path、role、identity、wire_version、采集机器
原始 UTC 时间和时钟语义。长度上限 65536 字节。

其后每条记录：

| 偏移 | 类型 | 内容 |
|---|---|---|
| 0 | uint64 LE | host_read_end_ns |
| 8 | uint64 LE | host_read_start_ns |
| 16 | uint32 LE | epoch |
| 20 | uint16 LE | UART 原帧长度（80 或 180） |
| 22 | uint16 LE | flags：gap=1、duplicate=2、reset=4、batched=8 |
| 24 | 原帧长度字节 | 完整 UART V2 帧，包含自身 CRC |

异步模式 start_ns 是请求提交时刻，end_ns 是完成回调时刻；在途请求含排队等待。
单个原始帧可能跨多个 USB 请求，记录的是完成该帧的那个请求。不得用这两个主机时刻
声称测出了 ADC 时间或精确 UART 传输时延。

`session.json` 保存文件清单、写入条数、录制队列丢弃、错误和终止后状态；`report.json`
另包含停止前在线状态、墙上经过时长（单调时钟）和进程 CPU 消耗。
停止后 connected=false 属于正常释放设备，不表示测试途中断线。

`read_recording()` 流式读回并验证记录长度、格式版本和每帧 CRC；尾部不完整会显式报错。
只保存 CRC 有效的帧，因此需结合报告中的坏帧/缺口/丢弃计数判断链路完整性，不能仅凭
录制文件内所有 CRC 正确就声称传输从未丢包。

## 实现依据

协议以相邻固件的 `docs/PROTOCOL_V2.md` 和编码器为准。高速 USB 实现依据
[libusb 异步 I/O 文档](https://libusb.sourceforge.io/api-1.0/group__libusb__asyncio.html)，
复用 [PyUSB 1.3.1 libusb1 后端定义](https://github.com/pyusb/pyusb/blob/v1.3.1/usb/backend/libusb1.py)。
固定依赖版本，避免内部 ctypes 布局随升级变化。

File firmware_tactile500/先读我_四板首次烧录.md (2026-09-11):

# 四板500Hz首次烧录

本轮约定：**先测试32点短线新版；每块板目标500完整帧/秒；传感器新转换率以后测量。**
短线=新版（旧NEW_HARDWARE=1），长线=旧版（=0）。
当前固件版本字节为 **0x21**，协议头为 **A5 5A**。

本轮已完成：GNU和Keil各六种板型构建、C核心与六板型向量测试、Python独立解码5项测试，
以及12份HEX的校验和/Flash范围/启动及中断向量检查。Keil均为0错误，
27条相同的C4008W编译选项提示已核对；这不等于实际板子已经通过测量。
每份HEX的SHA-256和检查结果见[构建清单](烧录_OSR256_20260910/先读我_OSR256烧录.md)。

## 先选择与板子相符的文件

Keil工程：[Tactile500.uvprojx](Project/MDK/Tactile500.uvprojx)。
左右手必须选不同Target。一个Target只烧到对应板子；不用把所有Target依次烧入同一块板。

| 板子 | Keil Target | Keil HEX（本轮重新构建） | 前5个UART字节 |
|---|---|---|---|
| 左手12点 | Tactile500_Left_Fingers12 | [左12 HEX](烧录_OSR256_20260910/OSR256_Tactile500_Left_Fingers12.hex) | A5 5A 50 21 08 |
| 右手12点 | Tactile500_Right_Fingers12 | [右12 HEX](烧录_OSR256_20260910/OSR256_Tactile500_Right_Fingers12.hex) | A5 5A 50 21 09 |
| 左手32点短线新版 | Tactile500_Left_Palm32_Short | [左32短线 HEX](烧录_OSR256_20260910/OSR256_Tactile500_Left_Palm32_Short.hex) | A5 5A B4 21 0E |
| 右手32点短线新版 | Tactile500_Right_Palm32_Short | [右32短线 HEX](烧录_OSR256_20260910/OSR256_Tactile500_Right_Palm32_Short.hex) | A5 5A B4 21 0F |

GNU构建的另一套HEX在[build/gcc](烧录_OSR256_20260910)，同样按板型选择。
两种编译器的HEX不要求逐字节一致，选定其中一种进行本轮烧录和记录。
长线旧版也有单独的左右Target，见[六种板型与通道表](docs/BOARD_VARIANTS_AND_CHANNEL_MAP.md)。

## 第一次测量顺序

1. 先连接一块准备测试的短线板，确认芯片为APM32F402RB、晶振16MHz及实际烧录器接线。
2. 在Keil选择相应Target，Rebuild应为0错误；使用该Target的新HEX下载并Verify。
   Flash算法为支持包的APM32F402_128.FLM，起始地址0x08000000。
3. 退出调试/断点，重新上电。初始化包含约1秒等待，随后自动连续输出，无需上位机发送启动命令。
4. 先看PA2（USART2 TX）或桥接前UART信号：921600、8N1，
   12点80字节一帧，32点180字节一帧，帧头起点间隔目标约2ms。
5. 上位机按V2协议解码10–30秒，核对板型/0x21、CRC、序号连续性和温度压力读数。
   再逐点按压核对通道。单板通过后，再接第二块，最后左12/左32/右12/右32四块接同一Hub。

上电后第一帧sequence从1开始；上位机如果晚打开，会从更大的序号开始收到，这是正常的。
帧内sample_time_us是一轮读取开始的时间，不是UART帧头时刻；精确发送周期用UART边沿测。

## 如果仍然显示“没有数据”

- PA2没有字节：先核对烧录/Verify、自由运行、板型芯片与晶振和供电。
- PA2有A5 5A帧而软件没有显示：核对CH340的UART设置、USB后端/接口占用，
  以及接收端是否支持V2。**旧BT/42 54协议解析器不会把这份固件识别成有效数据。**
- 能解帧但温压全部是启动哨兵（温度-32768、压力-8388608）：记录status，重点检查初始化/SPI与板型接线。
- status=0x01且fresh_mask=0时，先保留原始读数；这表示缺少DRDY新转换证据，
  单凭这一项不能判定断线，也不影响本轮对完整发包率的测量。

PyUSB属于上位机的CH340传输实现，MCU继续输出UART。此次没有修改上位机、驱动、Hub或机器人。
若使用相邻gpt6 V2上位机可按其V2接口对接；对别的软件必须先核对帧格式。

## 测完反馈这些信息

板型/HEX文件名、烧录Verify结果、是否有上述帧头、实际帧率、CRC错误/序号缺口、
status和fresh_mask、按压时哪些通道变化。先完成一块板的短测，再根据结果调整。

完整协议：[PROTOCOL_V2.md](docs/PROTOCOL_V2.md)。
用户给出的短线32通道显示位置表已保存在[通道映射](docs/BOARD_VARIANTS_AND_CHANNEL_MAP.md)，
MCU保持原始通道顺序，上位机显示时只换序一次。

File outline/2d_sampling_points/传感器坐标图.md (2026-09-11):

# 触觉传感器坐标图（Big 32 点 / Small 12 点）

生成时间：2026-09-11 21:24　|　坐标方向：**Y 轴向上**　|　**每块板左下角 = (0, 0)**

| 板 | 点数 | 平移量 (x_min, y_min) | 原点化后尺寸 宽 × 高 | 原始数据 SHA-256（前 16 位） |
|---|---:|---|---|---|
| Big 32 点 | 32 | (127.531, 55.6552) | 42.4614 × 27.5869 | `71dec34cf0a3b85e` |
| Small 12 点 | 12 | (105.8507, 71.1159) | 11.3550 × 29.9387 | `8bac68b0fdcc92e6` |

**本页所有坐标都是「左下角 = (0, 0)」的平移结果**：平移量 = 该板自己的 (x_min, y_min)，**只平移、不缩放、不旋转、不镜像**。12 点板与 32 点板用的是同一套规则，所以两板对齐到同一原点后可以直接比尺寸和节距。

原始绝对坐标（与 CSV 逐字一致）仍完整保留在常量模块的 `*_COORDS` / `*_XY` 里，随时可以取回。

---

## 一、图形版

> 三个面板都是**等比例**（1 单位 X = 1 单位 Y），形状未被拉伸；生成时逐面板校验 `ratio = 1.0000`。

### 1.1 总览

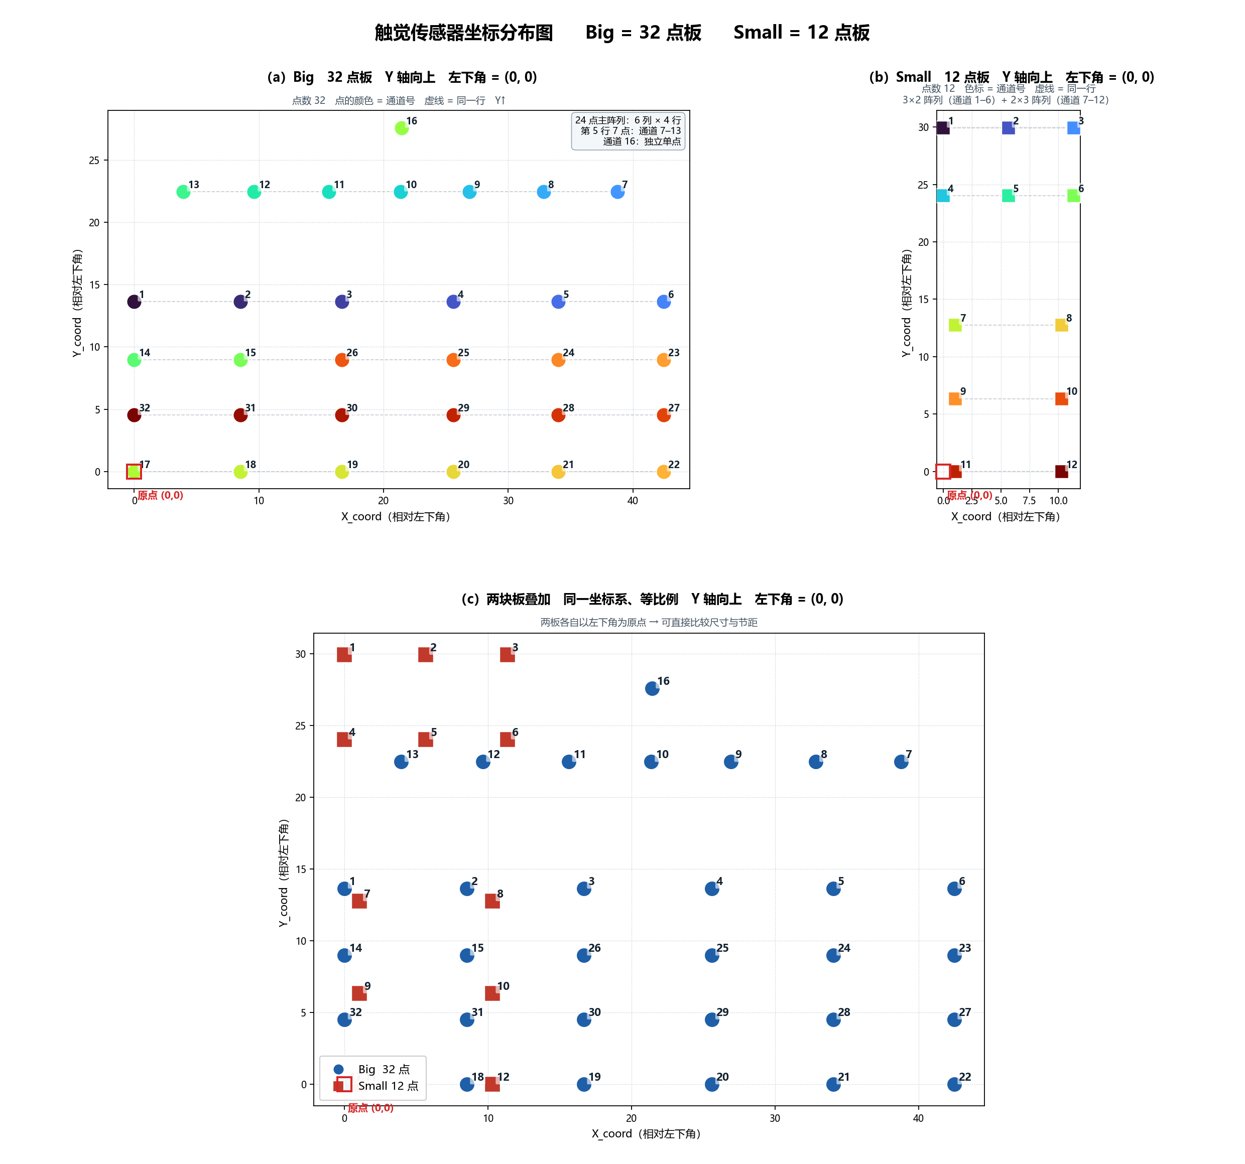
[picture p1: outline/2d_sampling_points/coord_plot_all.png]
总览


### 1.2 Big 32 点板

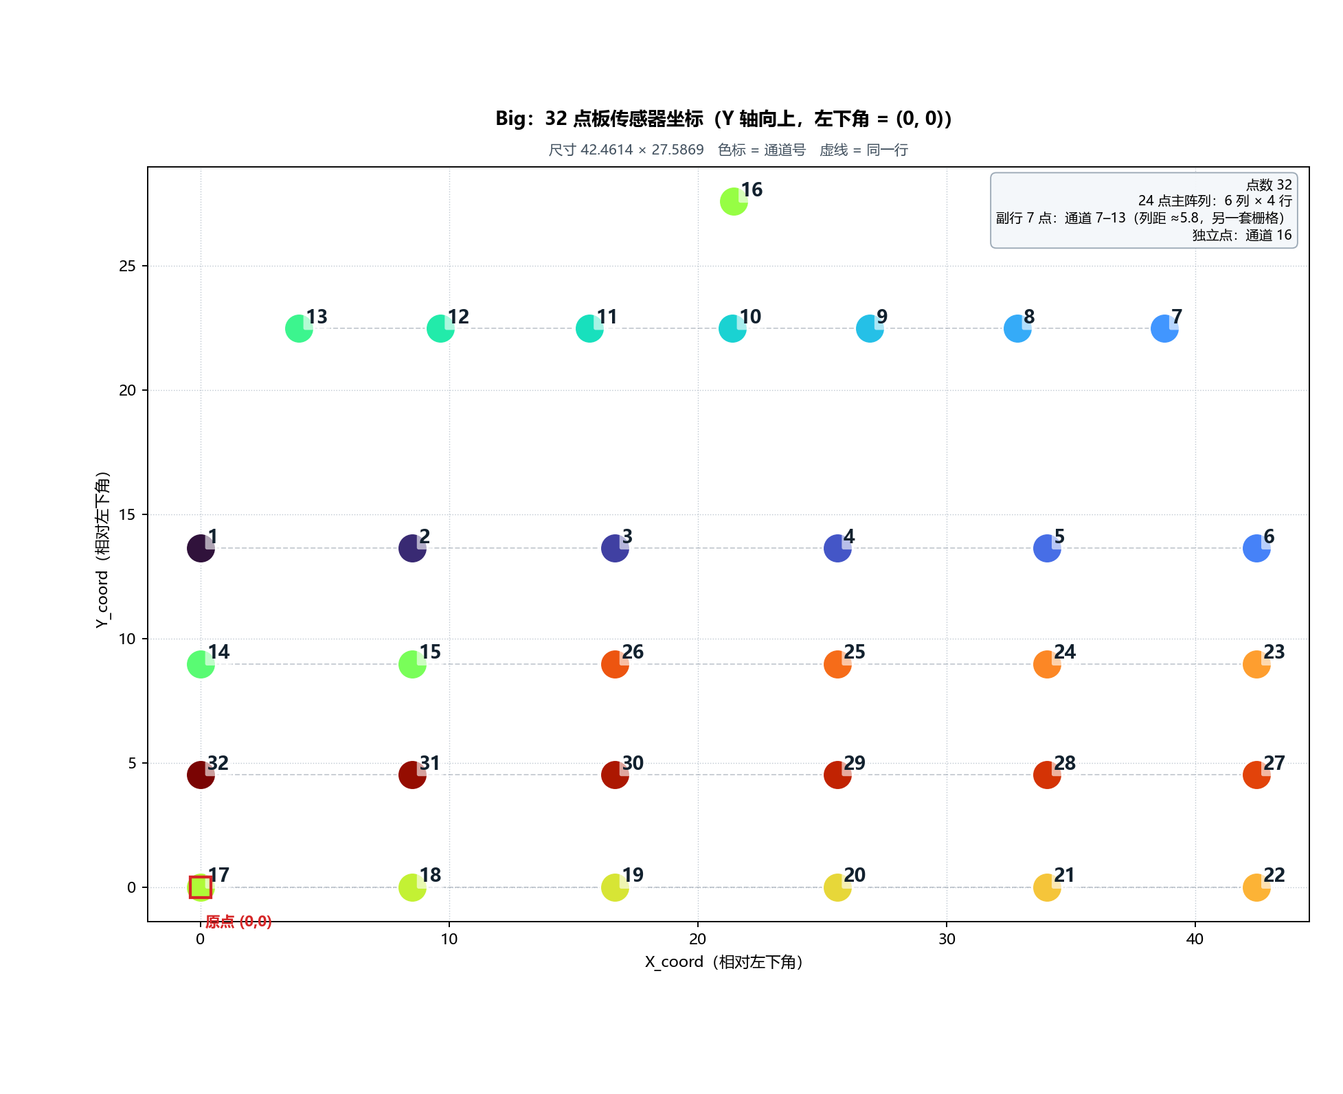
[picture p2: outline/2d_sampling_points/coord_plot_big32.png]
Big 32点


### 1.3 Small 12 点板

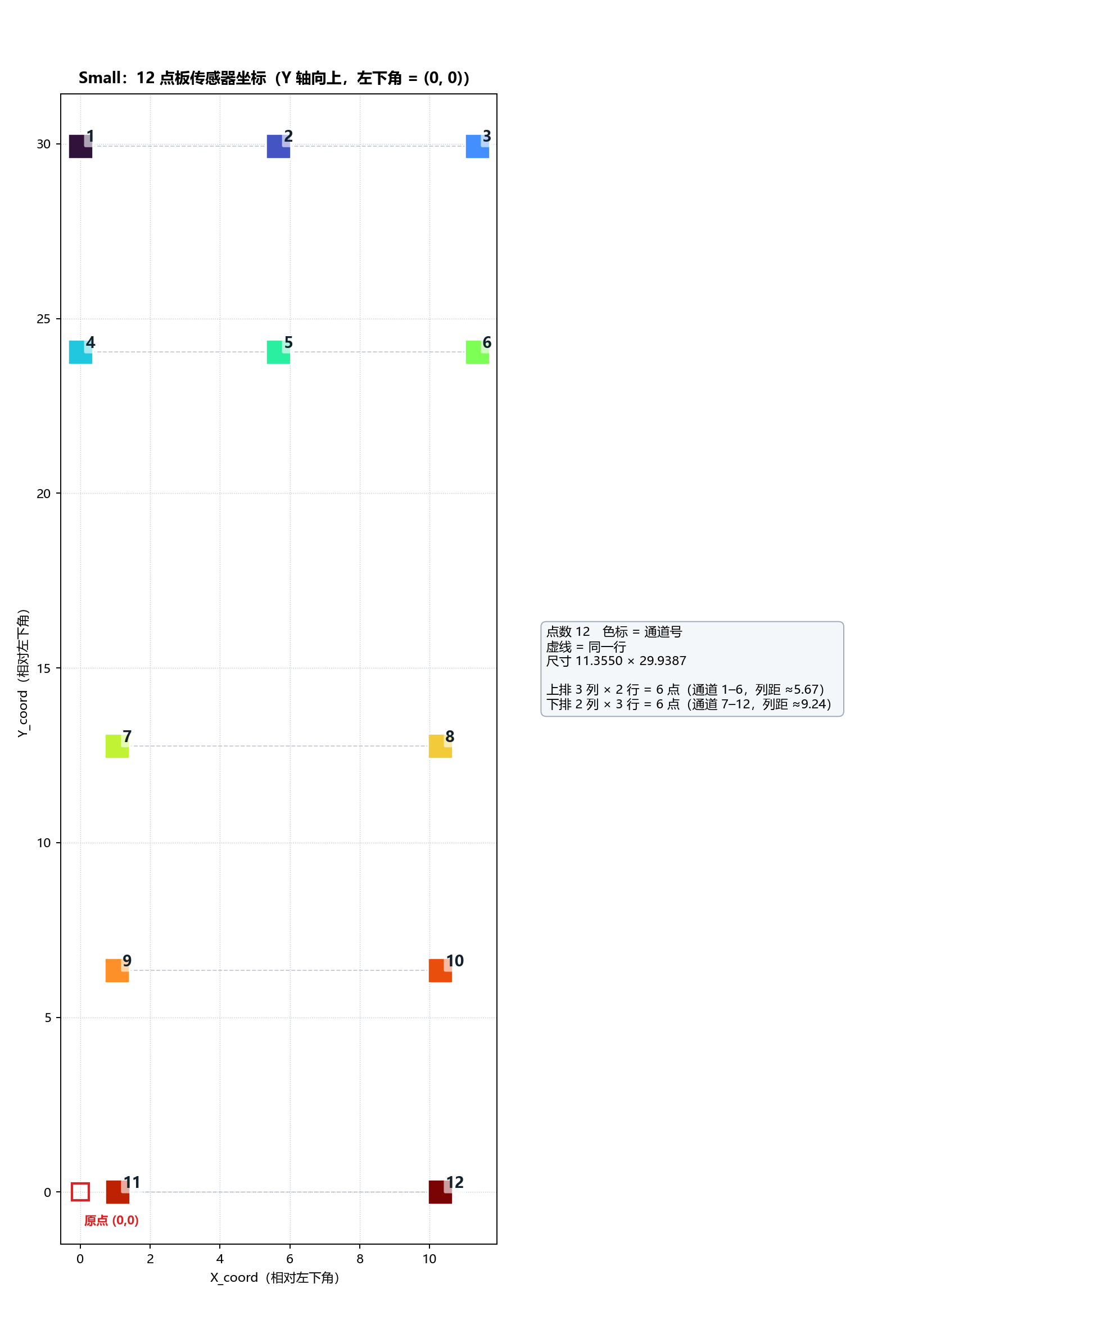
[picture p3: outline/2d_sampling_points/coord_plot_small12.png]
Small 12点


---

## 二、纯文本坐标图（不依赖图片）

字符列按比例对应 X、字符行按比例对应 Y（Y 轴向上），**原点在左下角**。**数字 = Big 板通道号，字母 = Small 板通道号**（A=1 … L=12）。
左侧刻度只标「该行真实存在的点」的 Y 值，空行不带刻度。

> 文字版只保证「列↔X、行↔Y 各自的比例关系」，两个方向是独立缩放的，所以它是**位置示意**，不是等比例图；等比例请看上面的 PNG。

### 2.1 Big 32 点板

```text
      X→  0    5   10   15  20   25  30   35  40
            ───────────────────────────────────────
27.59 │                   16
         │
22.47 │    13   12   11   10   9     8    7
         │
         │
         │
13.64 │1       2      3       4       5       6
         │
8.97 │14      15     26      25      24      23
         │
4.52 │32      31     30      29      28      27
         │
         │
0.00 │17      18     19      20      21      22
```

坐标范围：X 0.00 ~ 42.46　Y 0.00 ~ 27.59（原点化）

### 2.2 Small 12 点板

```text
      X→  0    5   10
            ────────────
29.94 │1    2    3
         │
         │
24.04 │4    5    6
         │
         │
         │
         │
12.76 │ 7       8
         │
         │
6.34 │ 9       10
         │
         │
0.00 │ 11      12
```

坐标范围：X 0.00 ~ 11.36　Y 0.00 ~ 29.94（原点化）

### 2.3 两块板叠加（各自左下角对齐到 (0, 0)）

```text
      X→  0      5      10     15      20     25     30     35     40
            ────────────────────────────────────────────────────────────
29.94 │A       B       C
         │
27.59 │                               16
         │
         │
         │
24.04 │D       E       F
22.47 │      13      12      11       10     9        8       7
         │
         │
         │
         │
         │
         │
         │
         │
13.64 │1           2           3            4           5           6
12.76 │  G            H
         │
         │
         │
8.97 │14          15          26           25          24          23
         │
         │
6.34 │  I            J
4.52 │32          31          30           29          28          27
         │
         │
         │
         │
0.00 │17K         18 L        19           20          21          22
```

坐标范围：X 0.00 ~ 42.46　Y 0.00 ~ 29.94（原点化）

> 读法提醒：两板共用原点后，Small 的 11 号 (1.058, 0.0004) 与 Big 的 17 号 (0, 0) 只差约 1 个单位，文字版里会紧挨着显示（`17K` = Big 的 17 + Small 的 K，`18 L` = Big 的 18 + Small 的 L）。字母是 Small、数字是 Big，位置本身没有挪动。

两板共用同一个原点，所以可以直接比较：**Big 宽 42.46、Small 宽 11.36**，高度接近（27.59 / 29.94）。

---

## 三、逐行坐标表（左下角 = (0, 0)）

行按 Y 升序（第 1 行在最下面，与图中 Y 轴向上一致）。通道号按 X 从左到右。X 从 0 起算。

### 3.1 Big 32 点板

| 行 | Y | 点数 | 通道号（左 → 右） | 逐个 X | 列间距 |
|---:|---:|---:|---|---|---|
| 1 | 0.0000 | 6 | `17 18 19 20 21 22` | 0.00 8.51 16.66 25.60 34.04 42.46 | 8.51 / 8.15 / 8.94 / 8.44 / 8.43 |
| 2 | 4.5245 | 6 | `32 31 30 29 28 27` | 0.00 8.51 16.66 25.60 34.04 42.46 | 8.51 / 8.15 / 8.94 / 8.44 / 8.43 |
| 3 | 8.9750 | 6 | `14 15 26 25 24 23` | 0.00 8.51 16.66 25.60 34.04 42.46 | 8.51 / 8.15 / 8.94 / 8.44 / 8.43 |
| 4 | 13.6408 | 6 | `1 2 3 4 5 6` | 0.00 8.51 16.66 25.60 34.04 42.46 | 8.51 / 8.15 / 8.94 / 8.44 / 8.43 |
| 5 | 22.4717 | 7 | `13 12 11 10 9 8 7` | 3.95 9.63 15.62 21.38 26.91 32.84 38.76 | 5.68 / 5.99 / 5.75 / 5.53 / 5.93 / 5.92 |
| 6 | 27.5869 | 1 | `16` | 21.45 | — |

### 3.2 Small 12 点板

| 行 | Y | 点数 | 通道号（左 → 右） | 逐个 X | 列间距 |
|---:|---:|---:|---|---|---|
| 1 | 0.0002 | 2 | `11 12` | 1.06 10.30 | 9.24 |
| 2 | 6.3410 | 2 | `9 10` | 1.06 10.30 | 9.24 |
| 3 | 12.7638 | 2 | `7 8` | 1.06 10.30 | 9.24 |
| 4 | 24.0372 | 3 | `4 5 6` | 0.00 5.67 11.36 | 5.67 / 5.69 |
| 5 | 29.9387 | 3 | `1 2 3` | 0.00 5.67 11.36 | 5.67 / 5.69 |

---

## 四、结构分析

### 4.1 Big 32 点板 = 24 点主阵列 + 7 点副行 + 1 个独立点

- **主阵列 6 列 × 4 行 = 24 点**：通道 `1, 2, 3, 4, 5, 6, 14, 15, 17, 18, 19, 20, 21, 22, 23, 24, 25, 26, 27, 28, 29, 30, 31, 32`。
  X 轴 14 个取值里有 6 个属主阵列，列距 ≈ 8.5；Y 为 55.6552 / 60.1797 / 64.6302 / 69.2960，行距 ≈ 4.5 → 单元格约 **8.5 × 4.5**。
- **副行 7 点**：通道 `7, 8, 9, 10, 11, 12, 13`，Y = 22.4717，列距 ≈ 5.8，与主阵列不是同一套栅格。
- **独立点**：通道 16 在 (21.4465, 27.5869)，两套栅格都对不上。

### 4.2 Small 12 点板 = 两块不同节距的子阵列

- **上排 3 列 × 2 行 = 6 点**：通道 `1, 2, 3, 4, 5, 6`，列距 ≈ 5.67。
- **下排 2 列 × 3 行 = 6 点**：通道 `7, 8, 9, 10, 11, 12`，列距 ≈ 9.24。

> 原始数据里通道 11 的 Y = 71.1163、通道 12 的 Y = 71.1159，相差 0.0004；原点化后分别是 0.0004 和 0.0000。两者视为同一行，表中该行 Y 取平均 0.0002（`SMALL_12_ROWS_REL` 的定义如此）。

### 4.3 两板关系（原点化后可直接比较）

| 项 | Big 32 点 | Small 12 点 |
|---|---|---|
| 平移量 (x_min, y_min) | (127.531, 55.6552) | (105.8507, 71.1159) |
| 尺寸 宽 × 高 | 42.4614 × 27.5869 | 11.3550 × 29.9387 |
| X 取值个数 | 14 | 6 |
| Y 取值个数（行数） | 6 | 6 |
| 主节距 | 列 ≈8.5 / 行 ≈4.5（主阵列）<br>副行 列 ≈5.8 | 上排 列 ≈5.67<br>下排 列 ≈9.24 |

两板共用同一个原点（各自左下角），所以可以直接看：**Big 明显更宽（42.5 vs 11.4）**，高度接近（27.6 vs 29.9）。

原始绝对坐标下两板的 X 区间是**不重叠**的（`BIG_AND_SMALL_X_OVERLAP = False`），Small 整体在 Big 左侧约 10 个单位 —— 这一点在原点化后不再体现，如需查看请用 `--raw` 出图。

---

## 五、常量模块 `sensor_coords.py`

坐标已写成 Python 常量，上位机可直接 import，不需要再解析 CSV：

```python
from sensor_coords import (
    # 原始绝对坐标（与 CSV 逐字一致）
    BIG_32_COORDS, SMALL_12_COORDS,        # ((通道号, X, Y), ...) 通道号 1..N
    BIG_32_XY, SMALL_12_XY,                # {通道号: (X, Y)}
    BIG_32_BOUNDS, SMALL_12_BOUNDS,        # (x_min, x_max, y_min, y_max)
    # 左下角 = (0, 0) 的原点化坐标
    BIG_32_COORDS_REL, SMALL_12_COORDS_REL,
    BIG_32_XY_REL, SMALL_12_XY_REL,
    BIG_32_ORIGIN, SMALL_12_ORIGIN,        # 被减掉的平移量
    BIG_32_SIZE, SMALL_12_SIZE,            # 宽 × 高
    BIG_32_BOUNDS_REL, SMALL_12_BOUNDS_REL,  # (0, 0, 宽, 高)
    # 栅格与结构
    BIG_32_X_AXIS, BIG_32_Y_AXIS, BIG_32_ROWS, BIG_32_ROWS_REL,
    BIG_32_MAIN_CHANNELS, BIG_32_SIDE_ROW, BIG_32_STANDALONE,
    SMALL_12_TOP_CHANNELS, SMALL_12_BOTTOM_CHANNELS,
    # 工具
    xy_for, xy_rel_for, coords_for, coords_rel_for,
    origin_for, size_for, bounds_for, bounds_rel_for, normalized_xy,
)

xy_for(17, 32)       # -> (127.531, 55.6552)   原始绝对坐标
xy_rel_for(17, 32)   # -> (0.0, 0.0)           Big 板左下角就是它
xy_rel_for(7, 32)    # -> (38.7583, 22.4717)   副行最右（原点化）
normalized_xy(32)    # -> {通道号: (u, v)}，u = X/宽, v = Y/高
```

| 常量 | 含义 |
|---|---|
| `BIG_32_COORDS` / `SMALL_12_COORDS` | **原始绝对坐标**，逐字来自 CSV |
| `BIG_32_COORDS_REL` / `SMALL_12_COORDS_REL` | **左下角 = (0, 0)** 的坐标 |
| `*_ORIGIN` | 该板被减掉的平移量 `(x_min, y_min)` |
| `*_SIZE` / `*_BOUNDS_REL` | 原点化后的宽高与包围盒 `(0, 0, 宽, 高)` |
| `*_XY` / `*_XY_REL` / `COORDS*_BY_CHANNEL_COUNT` | 按通道号 / 按通道数索引 |
| `*_BOUNDS` / `*_X_AXIS` / `*_Y_AXIS` | 原始包围盒与栅格轴 |
| `*_ROWS` / `*_ROWS_REL` | 逐行分组 `(Y, (通道号...))`，行内按 X 左→右 |
| `BIG_32_MAIN_CHANNELS` / `BIG_32_SIDE_ROW` / `BIG_32_STANDALONE` | Big 板三段结构 |
| `SMALL_12_TOP_CHANNELS` / `SMALL_12_BOTTOM_CHANNELS` | Small 板两块子阵列 |

除原始坐标外，其余常量全部**由原始表推导**（包括平移后的相对坐标），改原始表即自动同步，不会出现数据与派生值不一致。

---

## 六、待确认项

1. **Y 轴方向**：本图按「Y 轴向上」绘制。若来源是图像/屏幕坐标（Y 向下），跑 `python plot_coords.py --flip` 即可上下镜像；上位机可用 `normalized_xy(32, y_up=False)` 直接拿到屏幕坐标。
2. **`sensor_Number` 的口径**：是 MCU 原始通道 `ch01–ch32`，还是网页显示位置 `CH01–CH32`？后者需套 `嵌入式代码/Applications/Tactile500/docs/BOARD_VARIANTS_AND_CHANNEL_MAP.md` 里的短线换序表 `SHORT_POSITION_TO_CHANNEL`。

## 七、重新生成

```powershell
python make_sensor_coords.py            # CSV  ->  sensor_coords.py（常量）
python plot_coords.py                   # 常量 ->  PNG（左下角 = (0,0)）
python plot_coords.py --raw             # 常量 ->  PNG（原始绝对坐标）
python plot_coords.py --flip            # 常量 ->  PNG（Y 轴向下）
python plot_coords.py --verify-csv      # 校验常量与 CSV 逐字一致
python make_coord_md.py                 # 常量 ->  本 Markdown
python sensor_coords.py                 # 常量模块自检
```

`plot_coords.py` 会逐面板校验等比例（`ratio` 必须为 `1.0000`）以及说明框覆盖的数据点数（必须为 `0`）。

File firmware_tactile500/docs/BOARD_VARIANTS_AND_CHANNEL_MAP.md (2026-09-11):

# 四板配置与长短线通道位置

确认日期：2026-09-10，依据用户本次确认。

更新确认：用户在长线整套12点/32点实测后确认，现有长线、短线两套映射均正确。
12点两套共用同一排列；长线32点沿用固件已经排好的MCU通道顺序；短线32点采用下表。
长线片选排列不能再次作为上位机显示换序表。此次补充确认记录，不改变已安装wheel行为。
逐层列表与OSR建议见[变更与基准计划](CHANGELOG_AND_BENCH_PLAN.md)。

## 本轮目标与分工

四块板为左手12点、左手32点、右手12点、右手32点，各经一只CH340接入同一USB Hub。
第一阶段要求**每块板每秒发送500个完整帧，每帧含该板全部温度和压力通道**。
传感器每通道的新ADC转换率另行实测，不把重复读取等同于新转换。

嵌入式负责传感器读取、通道顺序、板型身份、2ms发送节拍、序号/时间/状态/CRC。
上位机负责CH340的USB枚举、桥接芯片配置、持续接收、V2解码、多板管理及显示。
MCU通过USART2发送921600/8N1字节流，不实现PyUSB。

仅从COM/tty读取切换成PyUSB直连、且UART参数和帧格式不变时，无须为此修改MCU。
若未来改了帧格式，上位机解码必须相应适配；这与USB传输层是两件事。
参考：[PyUSB官方教程](https://github.com/pyusb/pyusb/blob/master/docs/tutorial.rst)；
项目中相邻上位机的 `transport/pyusb_ch340.py` 已实现CH340控制请求与Bulk IN读取。
本次未修改上位机。

## 板型选择和线上身份

**短线是新版，长线是旧版。** 旧代码的 `NEW_HARDWARE=1` 对应32点短线新版，
`NEW_HARDWARE=0` 对应32点长线旧版。本工程通过Keil Target或GNU profile选择，
不要再加一个独立的NEW_HARDWARE开关，以免板型和身份不一致。
12点在协议中为 `cable=none`，不能把它的bit2=0解释成长线旧版。

| 实物板 | Keil Target | GNU profile | identity | 每帧 |
|---|---|---|---|---|
| 左手12点 | Tactile500_Left_Fingers12 | left_fingers12 | 0x08 | 80字节 |
| 右手12点 | Tactile500_Right_Fingers12 | right_fingers12 | 0x09 | 80字节 |
| 左手32点短线新版 | Tactile500_Left_Palm32_Short | left_palm32_short | 0x0E | 180字节 |
| 右手32点短线新版 | Tactile500_Right_Palm32_Short | right_palm32_short | 0x0F | 180字节 |
| 左手32点长线旧版 | Tactile500_Left_Palm32_Long | left_palm32_long | 0x0A | 180字节 |
| 右手32点长线旧版 | Tactile500_Right_Palm32_Long | right_palm32_long | 0x0B | 180字节 |

每帧偏移4的identity字节已经包含左右、12/32点和长短线，无需额外加字节。
身份由烧录的Target决定，MCU不会自动辨认实物长短线；烧错Target也会发出错误身份。
按身份区分这四种角色，不把Hub口号固定解释成左或右；更换Hub口不改变固件身份。

所有板独立计时、连续输出。四板各500帧/秒不等于四板同时采样，本轮不增加同步启动命令。

## 短线新版：网页显示位置取哪个原始通道

下面的CH和ch编号均从1开始，方向固定为“网页显示位置 → MCU原始通道”。
固件短线版仍按原始ch01..ch32顺序发送，不把这个位置表再次应用到固件的片选顺序。
上位机显示时，温度、压力和fresh位使用同一张表，每块板只转换一次。

| 网页显示 | MCU原始通道 | 网页显示 | MCU原始通道 |
|---|---|---|---|
| CH01 | ch13 | CH17 | ch26 |
| CH02 | ch15 | CH18 | ch24 |
| CH03 | ch05 | CH19 | ch32 |
| CH04 | ch03 | CH20 | ch30 |
| CH05 | ch01 | CH21 | ch19 |
| CH06 | ch07 | CH22 | ch21 |
| CH07 | ch09 | CH23 | ch25 |
| CH08 | ch11 | CH24 | ch23 |
| CH09 | ch10 | CH25 | ch17 |
| CH10 | ch08 | CH26 | ch28 |
| CH11 | ch02 | CH27 | ch27 |
| CH12 | ch04 | CH28 | ch18 |
| CH13 | ch12 | CH29 | ch20 |
| CH14 | ch16 | CH30 | ch22 |
| CH15 | ch14 | CH31 | ch29 |
| CH16 | ch06 | CH32 | ch31 |

便于对接的等价列表：

```python
SHORT_POSITION_TO_CHANNEL = (
    13, 15, 5, 3, 1, 7, 9, 11, 10, 8, 2, 4, 12, 16, 14, 6,
    26, 24, 32, 30, 19, 21, 25, 23, 17, 28, 27, 18, 20, 22, 29, 31,
)
# display[i] = mcu_raw[SHORT_POSITION_TO_CHANNEL[i] - 1]
```

此表由用户实测提供，并与相邻gpt6上位机现有表逐项核对一致；本轮尚未重新逐点按压验证。
长线旧版保留原有固件片选排列，见[协议说明](PROTOCOL_V2.md)；不能套用上面的短线显示表。

## 本次固件检查范围

保留已存在的0x21定时发送、双缓冲和UART TC后关闭DMA通道的逻辑，线上的帧格式不变。
配置中明确区分帧率与ADC转换率，并增加帧长、UART发送时间和采集预算的编译检查。
六个实际TACTILE_PROFILE分别编译测试程序，其输出帧由独立Python解码器检查身份、
通道数、长度、序号、时间、符号数和CRC；旧0x20向量继续用于协议兼容性测试。

此前OSR2048基线为A6=0x43、A7=0x83；本次已按用户指示改为
A6=0x40、A7=0x80（压力/温度OSR256），仍不覆盖EEPROM标定。
新档构建与烧录见[OSR256入口](../烧录_OSR256_20260910/先读我_OSR256烧录.md)。
读数在DRDY=0时仍发送，fresh位如实为0。依据本目录附带NSA2302手册第9、12、16页，
寄存器的新数据标志、OSR与温度标度需分别理解；第一阶段不以fresh全1作为通过条件。
历史实机记录与这次离线构建分开：本次生成的固件仍需由用户烧录后测量。

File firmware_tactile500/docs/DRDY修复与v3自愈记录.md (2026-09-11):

# DRDY 修复与 v3 自愈固件记录（2026-09-11）

## 结论速览

**协议未改**（V2 / `A5 5A` / `0x21`，帧长不变），**上位机无需修改**。
**Keil 工程直接编译本目录的源码**，无需额外的 HEX 交付目录：
打开 `Project/MDK/Tactile500.uvprojx` → 选 Target → Build，
产物在 `build/keil/<Target>/Tactile500_<Target>.hex`。

---

## 根因（datasheet 依据，已实测确证）

原固件初始化末尾写 `0xA5 = 0x88`，把 bit7 `DAC_on` 置 1。

| 依据 | 内容 |
|---|---|
| 第 11 页寄存器表 | `0xA5` bit7 `DAC_on`：**1 = Enable voltage output mode** |
| 第 17 页 6.3 节 | "Set 'DAC_on'=1 to get into the **analog output mode**（**no matter what 'CMD' registers contents**）。自主执行 64 次压力 + 1 次温度转换" |
| 第 18-19 页 6.5.1 节 | INT/DRDY 只在**命令驱动**的四种工作模式下定义；模拟输出模式不在其中 |

**v1 实测证实**：改为命令驱动单次转换后，DRDY 立即开始工作。

## 实测发现：真实转换时间 2~4 ms

v1 实机（G2，四板，120 秒）中，所有可用通道的 `fresh` 比例**精确等于 0.5000**，
即每隔一帧才有一次新转换：

```
帧N   : DRDY=1 → 读数 → 触发
帧N+1 : DRDY=0（仍在转换）→ 跳过
帧N+2 : DRDY=1 → 读数 → 触发
```

推论：**单次转换模式下一次完整转换（含每次 power-up）耗时 2~4 ms**，500 Hz 帧率下
真实新测量约 250 Hz。

这解释了模拟输出模式为何能到 ~489 次/秒（自主连续转换、无每次上电开销），
但代价是 DRDY 永不置位。**两者是本质权衡。**

> **注意**：即使 v3 完全正常，`fresh` 比例预期仍是约 **0.5**，不是 1.0。
> 这是 NSA2302 单次模式的真实能力，不是缺陷。

## 已解决：部分通道初始化失败（v3 自愈）

v1（SPI 7.5 MHz）与 v2（3.75 MHz）实机都出现 `init_error`，
失败通道**集中在 SPI1 侧**（`channel < COUNT/2`）：32 点板为 ch0–15，12 点板为 ch0–5。

### 推断（v3 实测支持）

板载 EEPROM 被早期固件烧入了 `0xA5 = 0x88`（legacy 固件用自动模式烧写，见下）。
上电时 EEPROM 自动加载 → 芯片进入模拟输出模式；固件再写 `0xA5 = 0x08` 切换。
**若该写入未生效**，芯片留在模拟输出模式，此时写 `0x30` 触发命令会被忽略
（6.3 节 "no matter what CMD registers contents"），DRDY 永不置位 → `fresh` 恒 0。

**这一个原因同时解释「初始化校验失败」与「fresh 恒 0」——所以它们总是同一批通道。**

### v3 的应对：运行中自愈

```
某通道连续 4 帧 DRDY = 0
    ↓
自动重写整套配置（0xA4 / 0xA5 / 0xA6 / 0xA7）
    ↓
回读 0xA5 存入 g_tactile_diag.a5_rb_latest[ch]
    ↓
重新触发转换
```

- 每帧最多恢复 `TACTILE_RECOVER_MAX_PER_FRAME`（8）个通道，不挤占 1750 µs 扫描预算
- **不再因初始化校验失败而永久跳过通道**；实测能出数后自动撤销 `init_error` 标记
- 初始化末尾对失败通道完整重写一遍再回读（上电瞬间 SPI 未稳，一次失败不代表芯片坏）

**实机结果：50 个失效通道全部恢复，`init_error` 归零。**

> 若要进一步确认因果链，可在 Keil 观察 `g_tactile_diag.a5_rb_latest[]`：
> 若自愈时读到 `0x88` 而自愈后转为 `0x08`，则模式锁定推断成立。

---

## 版本演进

| 版本 | SPI | 改动 | 实测结果 |
|---|---|---|---|
| v1 | 7.5 MHz | 去掉 `DAC_on`，改 `0x30` 触发，流水线采集 | DRDY 修复成功；但 SPI1 侧 init 失败 |
| v2 | 3.75 MHz | 降速 + 初始化回读诊断 | G2 实测 `init_error` 仍存在 |
| **v3** | 3.75 MHz | **+ 运行中自愈** | ✅ **全部通道恢复，问题解决（见下）** |

### v3 实机验证结果（2026-09-11，G2，四板）

| 指标 | v1 / v2 | **v3** |
|---|---|---|
| `init_error` | 100% 的帧都有 | **0 / 4964 —— 完全消失** |
| `fresh = 0` 的通道数 | **50** | **0** |
| `fresh` 正常通道 | 部分（32点板 16/32，12点板 6/12） | **32/32、12/12、32/32、12/12 全部** |
| 帧率 | 500 Hz | 500 Hz |
| `missing_slots` / `duplicates` | 0 / 0 | 0 / 0 |
| `status` | `not_all_fresh` + `init_error` | 只剩 `not_all_fresh` |

逐板（本次接的是长线版 32 点板）：

| 路径 | identity | 板型 | 通道 | init_error | fresh 正常 |
|---|---|---|---|---|---|
| `1-1.1` | `0x0B` | 右手 32 点长线 | 32 | 0 | 32/32 |
| `1-1.2` | `0x09` | 右手 12 点 | 12 | 0 | 12/12 |
| `1-1.3` | `0x0A` | 左手 32 点长线 | 32 | 0 | 32/32 |
| `1-1.4` | `0x08` | 左手 12 点 | 12 | 0 | 12/12 |

**`fresh ≈ 0.5000` 是健康值**，正是前文「真实转换时间 2~4 ms」的必然结果，
不是缺陷。个别通道略高（如 0.753）属正常波动。

### v3 的自愈机制

```
某通道连续 4 帧 DRDY = 0
    ↓
自动重写整套配置（0xA4 / 0xA5 / 0xA6 / 0xA7）
    ↓
回读 0xA5 存入 g_tactile_diag.a5_rb_latest[ch]
    ↓
重新触发转换
```

- 每帧最多恢复 `TACTILE_RECOVER_MAX_PER_FRAME`（8）个通道，不挤占 1750 µs 扫描预算
- **不再因初始化校验失败而永久跳过通道**；实测能出数后自动撤销 `init_error` 标记
- 初始化末尾对失败通道完整重写一遍再回读（上电瞬间 SPI 未稳，一次失败不代表芯片坏）

---

## 编译期配置（当前值）

| 宏 | 值 | 说明 |
|---|---|---|
| `TACTILE_FRAME_RATE_HZ` | 500 | 帧率 |
| `TACTILE_UART_BAUDRATE` | 921600 | |
| `TACTILE_SPI1_PRESCALER` | `_32` | 120/32 = **3.75 MHz** |
| `TACTILE_SPI2_PRESCALER` | `_16` | 60/16 = **3.75 MHz** |
| `TACTILE_SENSOR_SYS_CONFIG` | `0x08` | **`DAC_on = 0`**（关键修正） |
| `TACTILE_SENSOR_PCH_CONFIG` | `0x40` | 压力增益 32×、OSR 256 |
| `TACTILE_SENSOR_TCH_CONFIG` | `0x80` | 内部温度、增益 1×、OSR 256 |
| `TACTILE_SENSOR_CMD_REG` | `0x30` | COMMAND 寄存器 |
| `TACTILE_SENSOR_CMD_SENSOR` | `0x09` | `Sco=1`, `CMD=001` 单次传感器转换 |
| `TACTILE_SENSOR_CMD_COMBINED` | `0x0A` | `Sco=1`, `CMD=010` 组合转换 |
| `TACTILE_SENSOR_TEMP_EVERY` | 64 | 每 64 帧刷新一次温度 |
| `TACTILE_RECOVER_AFTER_MISSES` | 4 | 连续 N 帧未就绪即自愈 |
| `TACTILE_RECOVER_MAX_PER_FRAME` | 8 | 每帧自愈上限 |

SPI 提速依据：datasheet 第 23 页 Table 7.2，`f_sclk` 最大 **10 MHz**（负载 25 pF）。
1.875 MHz 不够用——每帧 416 字节需 1.78 ms，超过 1750 µs 扫描预算；3.75 MHz 只需 0.89 ms。

---

## 诊断量（Keil Watch 窗口添加 `g_tactile_diag`）

| 字段 | 含义 | 期望 |
|---|---|---|
| **`a5_rb_latest[ch]`** | **自愈时重读的 0xA5** | `0x08`=写入生效；`0x88`=仍是模拟输出模式；`0x00`=SPI 失败 |
| **`recovered_mask`** | 自愈成功的通道位图 | 非 0 说明自愈起作用 |
| `recover_attempts` | 累计自愈次数 | — |
| `stuck_mask` | 最近一帧仍无 fresh 的通道 | 越小越好 |
| `init_fail_mask` | 初始化失败的通道位图 | 0 最佳 |
| `init_a5_rb[]` / `init_a6_rb[]` / `init_a7_rb[]` | 各通道回读值 | 分别 `0x08` / `0x40` / `0x80` |
| **`prime_conversion_us`** | **真实转换时间** | 预期 2000~4000 µs |
| `prime_timeout` | 上电等待是否超时 | 0 |
| `full_fresh_frames` / `total_frames` | fresh 全满帧占比 | 见上文说明 |

---

## 早期固件写入的标定值（重要背景）

`reports/firmware_hardware_audit_20260910/legacy_original_main.c` 第 747–768 行，
早期固件执行过**整套标定写入 + EEPROM 自动烧写**：

```c
Spi_WriteReg(addr, 0xa4, 0x00);
Spi_WriteReg(addr, 0xa5, 0x88);    // ← 模拟输出模式，已烧进 EEPROM
Spi_WriteReg(addr, 0xa6, 0x43);    // ← OSR=2048
Spi_WriteReg(addr, 0xa7, 0x83);    // ← OSR=2048
Spi_WriteReg(addr, 0xaa, 0x00);    // ┐
Spi_WriteReg(addr, 0xab, 0x7A);    // │ 温度传感器标定系数 MT0 / KT
Spi_WriteReg(addr, 0xac, 0x2F);    // │
Spi_WriteReg(addr, 0xad, 0x00);    // ┘
Spi_WriteReg(addr, 0x6a, 0x40);    // ┐ 自动模式 EEPROM 烧写
Spi_WriteReg(addr, 0x6c, 0x6a);    // ┘
DAL_Delay(1000);                   /* 等待EEPROM写入1秒 */
```

按 datasheet 6.5.1.7 节，自动模式会把**所有** EEPROM 寄存器烧入。
因此当前板载 EEPROM 的 `0xA5` 为 `0x88`，`0xA6` 为 `0x43`。

**现固件不再写、也不烧写这些标定值**；压力标定系数（`0xAE`~`0xBC`）未被 legacy 显式改动，
自动模式只是回写原值，应完好。

### EEPROM 标定寄存器地图（datasheet 第 13–14 页）

EEPROM 共 32 字节，地址 `0xA0`~`0xBF`：

| 地址 | 名称 | 含义 | LSB | 范围 |
|---|---|---|---|---|
| `0xAA`/`0xAB` | `MT0` | 温度偏置系数 | 1/2¹⁵ | (−1, +1) |
| `0xAC`/`0xAD` | `KT` | 温度灵敏度系数 | 1/2¹⁰ | (−32, +32) |
| `0xAE`/`0xAF` | `CNT_OFF` | T₀ 处偏置 | 1/2¹⁵ | (−1, +1) |
| `0xB0`/`0xB1` | `CTC1` | 一阶温度偏置系数 | 1/2²² | ±0.00781 |
| `0xB2`/`0xB3` | `CTC2` | 二阶温度偏置系数 | 1/2²⁷ | ±6.1e−5 |
| `0xB3`~`0xB5` | `S0` | T₀ 处灵敏度 | 1/2¹³（无符号） | (0, 2) |
| `0xB5`/`0xB6` | `STC1` | 一阶温度灵敏度系数 | 1/2²⁰ | ±0.00781 |
| `0xB7`/`0xB8` | `STC2` | 二阶温度灵敏度系数 | 1/2²⁵ | ±1.5e−5 |
| `0xB8`/`0xB9` | `KS` / `KSS` | 二/三阶非线性系数 | 1/2¹¹ | (−0.25, +0.25) |
| `0xBA` | `KS_scale`/`KSS_scale` | 非线性系数 ×4 标志 | — | — |
| `0xBB`/`0xBC` | `B0` | 非线性标定参考压力点 | 1/2¹⁵ | (−1, 1) |

**标定模型**（datasheet 第 14 页）：内置 DSP 支持**偏置与灵敏度的二阶温度漂移补偿**，
以及**输出非线性的三阶补偿**。系数存在 EEPROM，上电自动加载。

**待核实**：这些系数默认值均为 `0x00`（尤其 `S0`）。若 `S0 = 0` 则标定输出应为 0，
但实测值在正常变化，故需读出实际值判断标定是否真正生效。
可在 `TactileDiag` 中扩展寄存器 dump 来核实。

---

## 回退

原始 OSR256 固件在 [`../烧录_OSR256_20260910/`](../烧录_OSR256_20260910/先读我_OSR256烧录.md)，
未被覆盖。重烧即可恢复原行为（`fresh_mask` 回到恒 0，数据更新率恢复约 489/秒）。

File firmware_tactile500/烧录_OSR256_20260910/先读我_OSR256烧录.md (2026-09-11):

# OSR256 本轮烧录入口

2026-09-10。已按用户指示将压力、温度OSR都改为256：A6=0x40，A7=0x80。
压力增益仍32倍，内部温度增益仍1倍。500 Hz帧率、921600/8N1、协议0x21、通道映射及标定系数保持不变。
尚未烧录实物或测量256档重复率。

## 目前这套长线组件

最近识别的是右12点0x09、右32点长线0x0B；本轮继续用对应Target：

| 板子 | Keil Target | 已编译的OSR256 HEX |
|---|---|---|
| 右12点 | Tactile500_Right_Fingers12 | [右12点OSR256](OSR256_Tactile500_Right_Fingers12.hex) |
| 右32点长线 | Tactile500_Right_Palm32_Long | [右32点长线OSR256](OSR256_Tactile500_Right_Palm32_Long.hex) |

Keil工程：[Tactile500.uvprojx](../Project/MDK/Tactile500.uvprojx)。
源码参数：[tactile_config.h](../Include/tactile_config.h)。

使用Keil时选择对应Target，Rebuild后下载并Verify；各Target的标准build/keil输出也已重建为256档。
如果烧录工具直接选HEX，使用本目录带OSR256前缀的对应文件。
烧完退出调试并重新上电，让启动流程重新写入并校验A6/A7。初始化包含约1秒等待。

协议版本仍为0x21，这是正常的；协议中没有独立OSR字段，所以不能仅凭网页显示0x21确认新档位。
本轮以正确HEX、烧录Verify及重新上电为前提记录配置；固件启动仍会读回校验A6/A7。

## 其他板型

| 板子 | HEX |
|---|---|
| 左12点 | [左12点OSR256](OSR256_Tactile500_Left_Fingers12.hex) |
| 左32点长线 | [左32点长线OSR256](OSR256_Tactile500_Left_Palm32_Long.hex) |
| 左32点短线 | [左32点短线OSR256](OSR256_Tactile500_Left_Palm32_Short.hex) |
| 右32点短线 | [右32点短线OSR256](OSR256_Tactile500_Right_Palm32_Short.hex) |

12点不区分长短组件，32点按实物选择长/短线版本。

## 本轮验证

- Keil六个Target：均0错误，各27条原有C4008W提示，无其他警告。
- GNU六板型构建成功。
- 现有C核心测试、六板型向量测试、Python独立解码5项测试通过。
- 两套共12份新HEX：校验和、Flash范围、初始栈及复位向量检查通过，均与原OSR2048文件不同。
- 本目录六份HEX来自本轮Keil构建；SHA256与配置记录：[manifest.json](manifest.json)。
- 旧2048档配置、12份HEX及构建清单已打包备份，路径记在manifest.json中。
- 上位机wheel与G1网页服务本轮未修改，未自动开始录制。

烧录接好后，再开始这一档的测量：先核对在线身份与状态，再录制包含固定载荷及动态按压的数据，比较帧率、逐通道重复率和噪声。本步骤尚未执行。

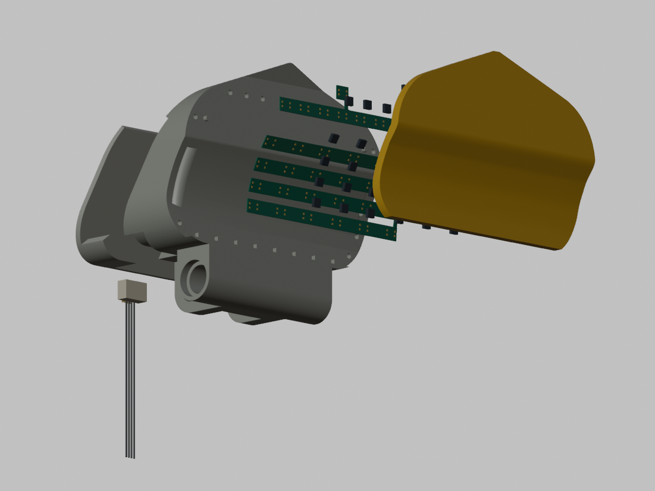
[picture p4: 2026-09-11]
outline/3d_structure/editable_gripper_preview/blender/gripper-32.png

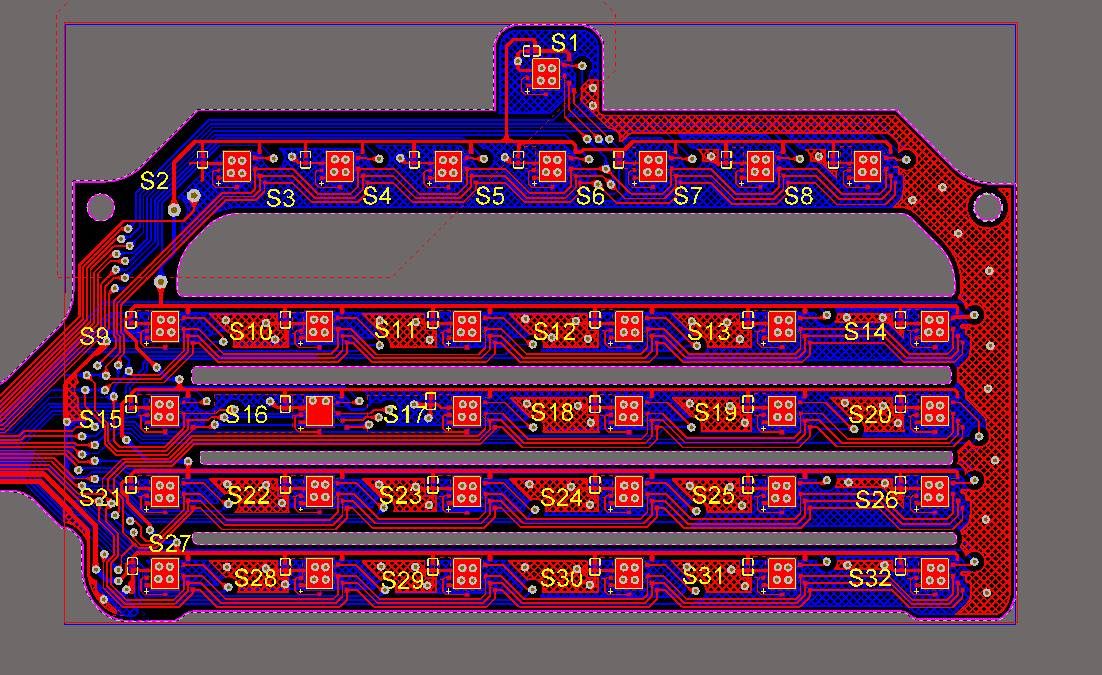
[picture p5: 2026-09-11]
outline/3d_structure/editable_gripper_preview/reference-pcb.png

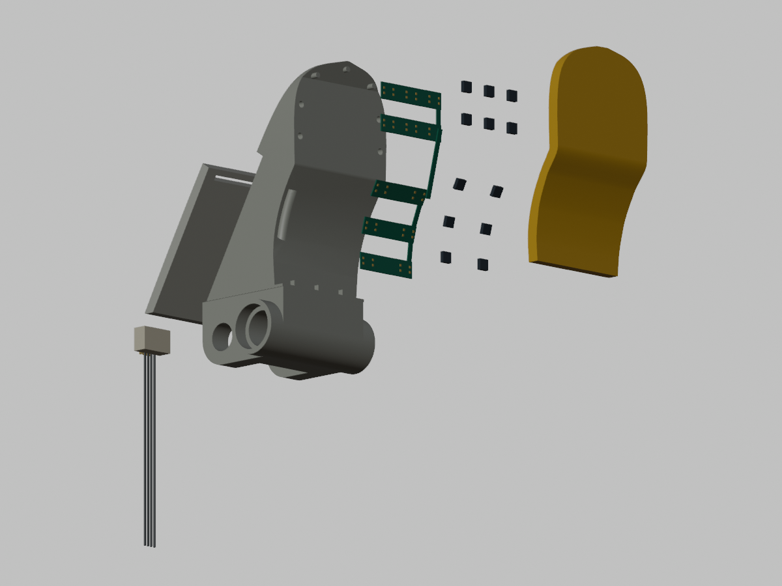
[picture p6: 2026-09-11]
outline/3d_structure/editable_gripper_preview/blender/gripper-12.png

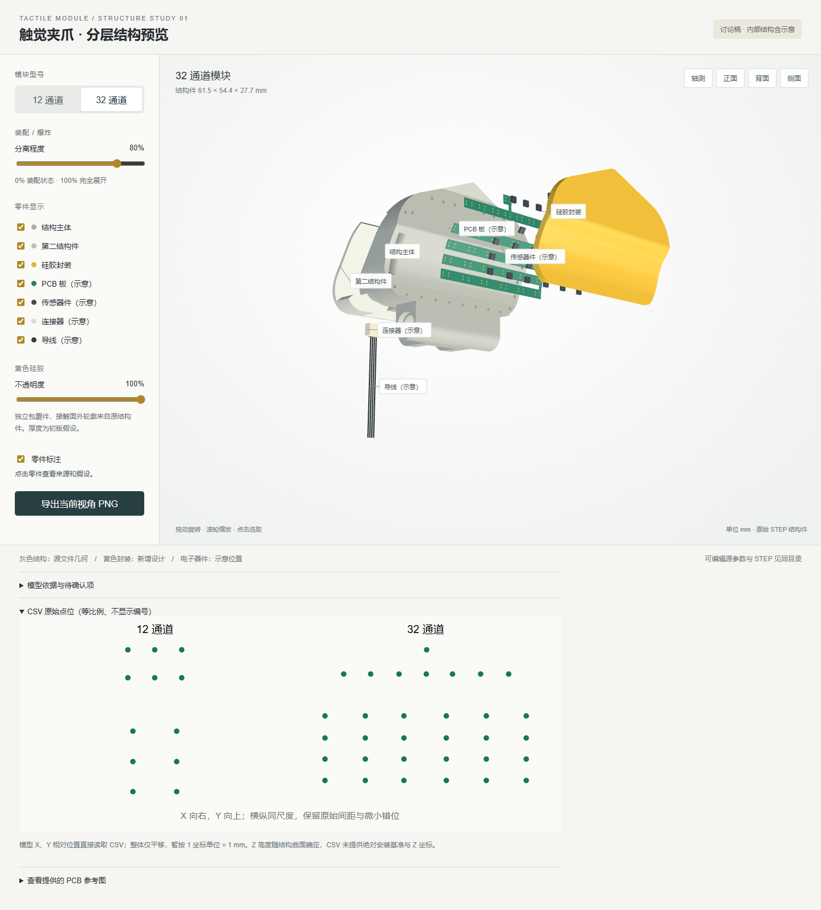
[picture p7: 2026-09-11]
outline/3d_structure/editable_gripper_preview/preview-32-exploded.png

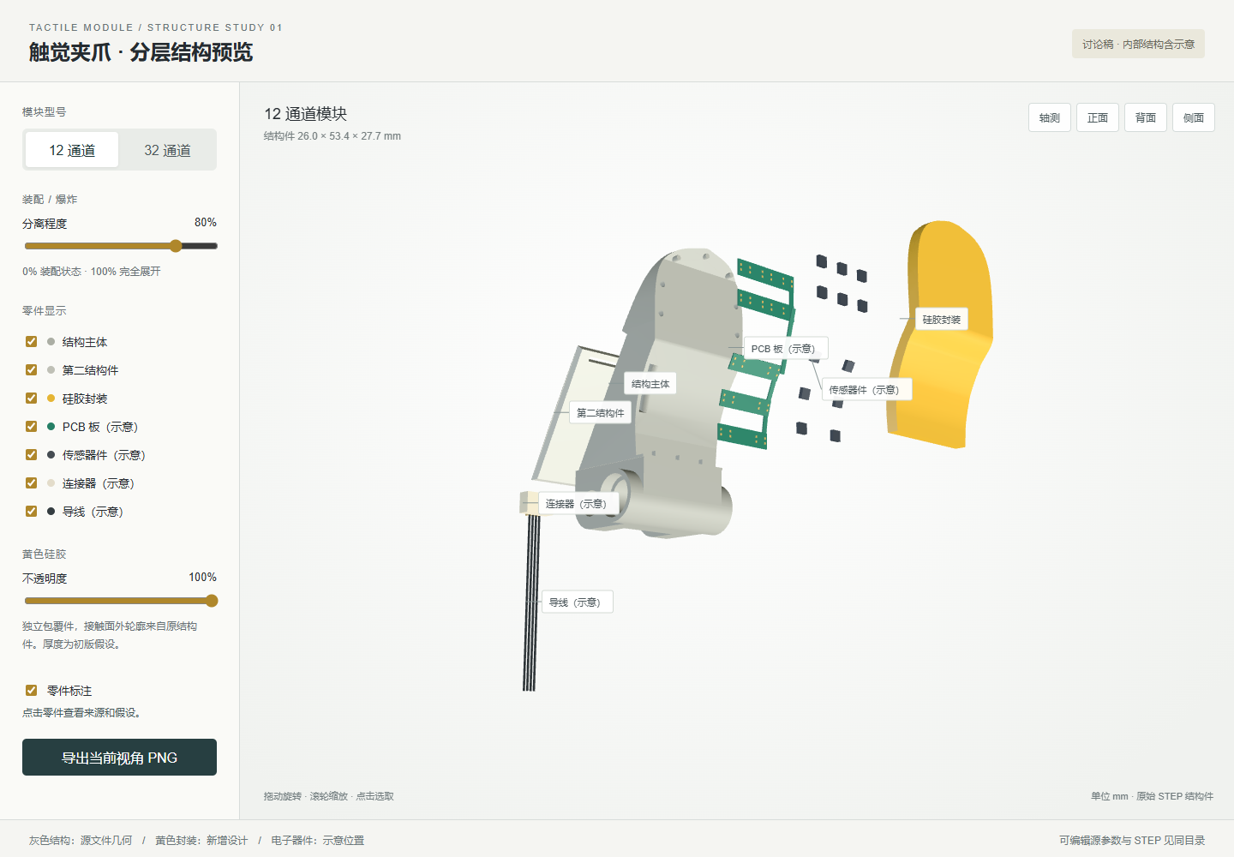
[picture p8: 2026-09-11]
outline/3d_structure/editable_gripper_preview/preview-12-exploded.png

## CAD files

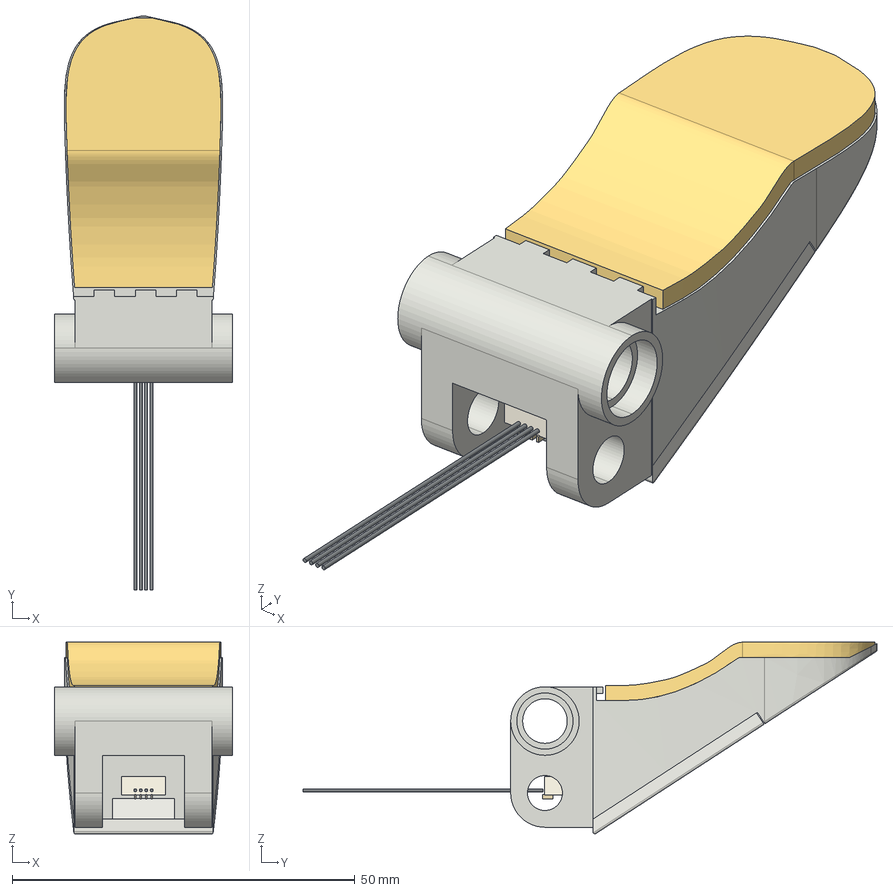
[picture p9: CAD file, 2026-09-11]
outline/3d_structure/editable_gripper_preview/cad/12/gripper-12-assembled.step
26.0 x 83.7 x 27.9 mm
Structural_body
Source_cover
Silicone_cap
PCB_illustrative
Solder_pads_illustrative
Connector_illustrative
Connector_pins_illustrative
Sensor_01_illustrative
Sensor_02_illustrative
Sensor_03_illustrative
Sensor_04_illustrative
Sensor_05_illustrative
Sensor_06_illustrative
Sensor_07_illustrative
Sensor_08_illustrative
Sensor_09_illustrative
Sensor_10_illustrative
Sensor_11_illustrative
Sensor_12_illustrative
Wire_1_illustrative
Wire_2_illustrative
Wire_3_illustrative
Wire_4_illustrative

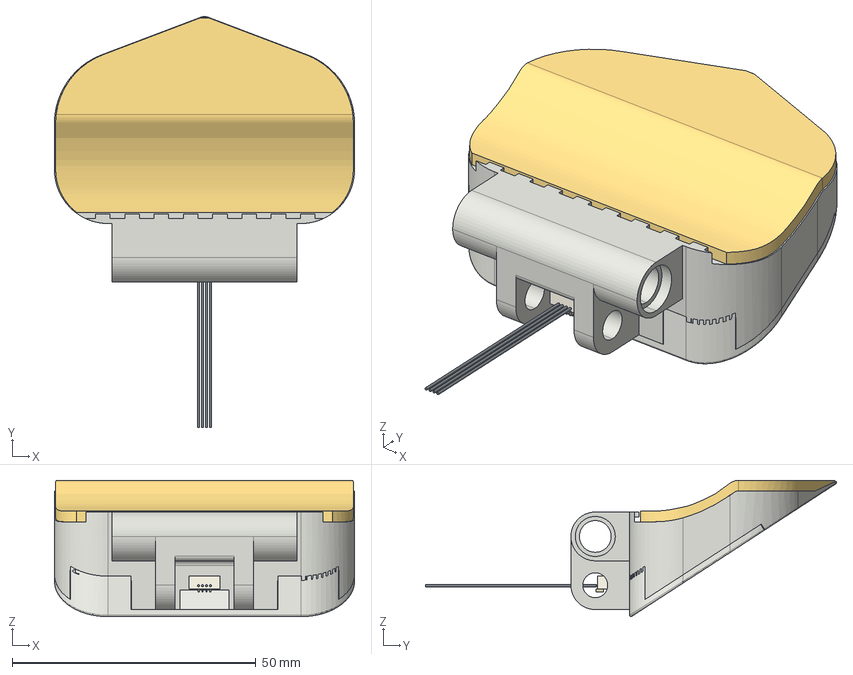
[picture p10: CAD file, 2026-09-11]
outline/3d_structure/editable_gripper_preview/cad/32/gripper-32-assembled.step
61.5 x 84.2 x 27.9 mm
Structural_body
Source_cover
Silicone_cap
PCB_illustrative
Solder_pads_illustrative
Connector_illustrative
Connector_pins_illustrative
Sensor_01_illustrative
Sensor_02_illustrative
Sensor_03_illustrative
Sensor_04_illustrative
Sensor_05_illustrative
Sensor_06_illustrative
Sensor_07_illustrative
Sensor_08_illustrative
Sensor_09_illustrative
Sensor_10_illustrative
Sensor_11_illustrative
Sensor_12_illustrative
Sensor_13_illustrative
Sensor_14_illustrative
Sensor_15_illustrative
Sensor_16_illustrative
Sensor_17_illustrative
Sensor_18_illustrative
Sensor_19_illustrative
Sensor_20_illustrative
Sensor_21_illustrative
Sensor_22_illustrative
Sensor_23_illustrative
Sensor_24_illustrative
Sensor_25_illustrative
Sensor_26_illustrative
Sensor_27_illustrative
Sensor_28_illustrative
Sensor_29_illustrative
Sensor_30_illustrative
Sensor_31_illustrative
Sensor_32_illustrative
Wire_1_illustrative
Wire_2_illustrative
Wire_3_illustrative
Wire_4_illustrative

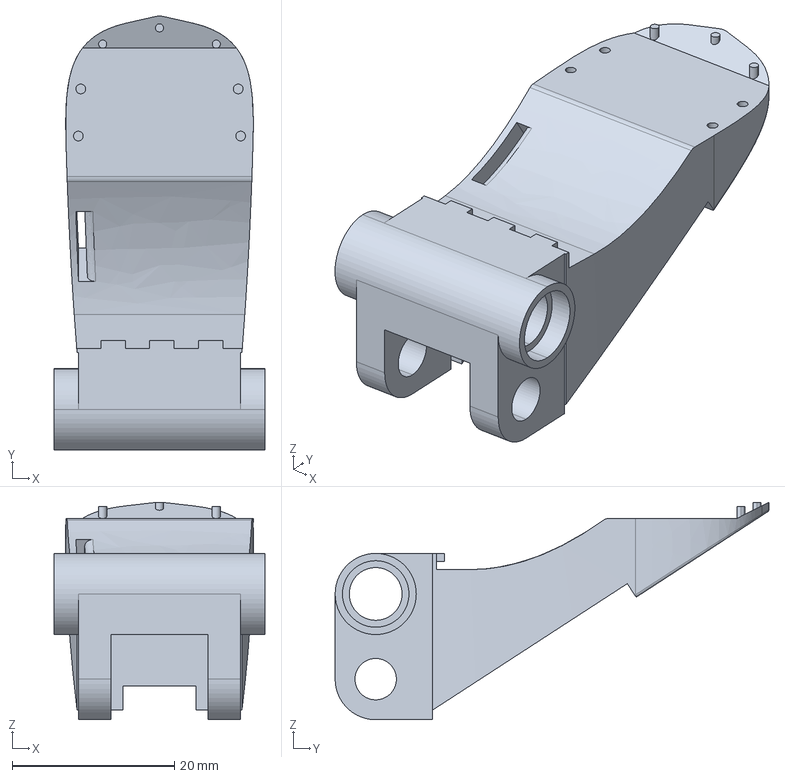
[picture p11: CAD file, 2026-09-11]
outline/3d_structure/editable_gripper_preview/cad/12/Structural_body.step
26.0 x 53.4 x 26.8 mm

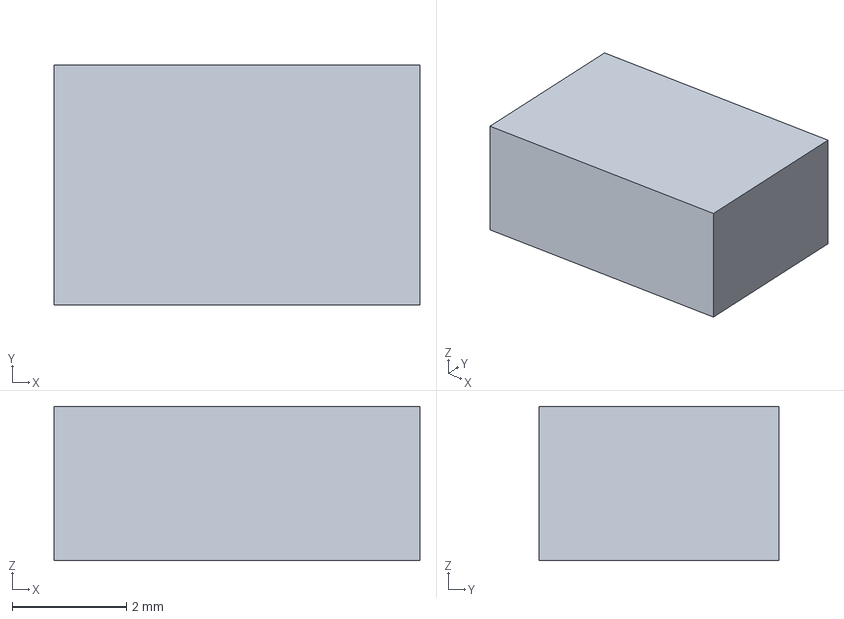
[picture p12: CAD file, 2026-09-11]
outline/3d_structure/editable_gripper_preview/cad/32/Connector_illustrative.step
6.40 x 4.20 x 2.70 mm

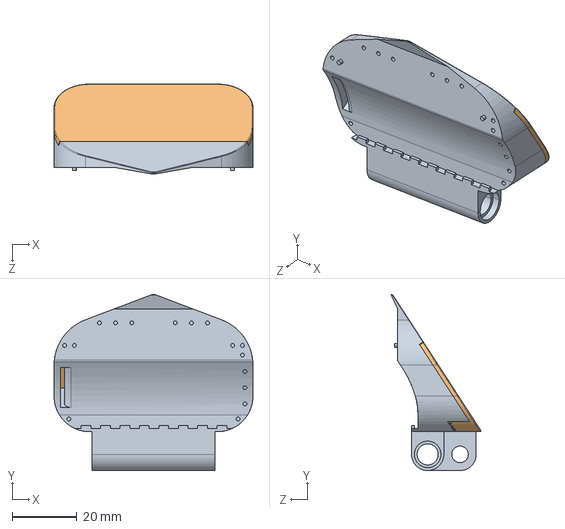
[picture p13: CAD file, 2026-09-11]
outline/3d_structure/onebody-32-jiegoujian.STEP
61.5 x 54.4 x 27.7 mm

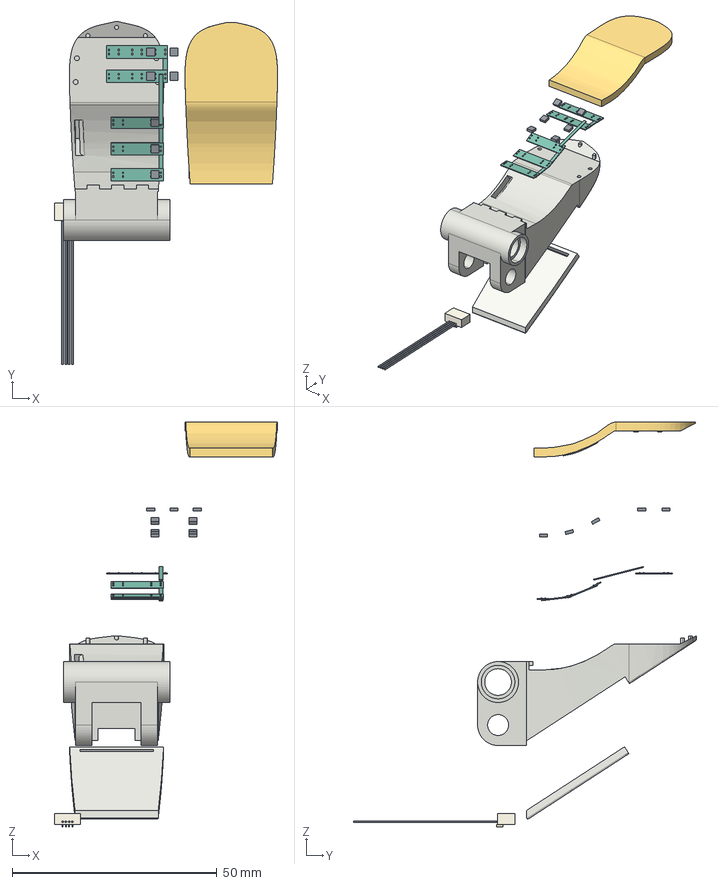
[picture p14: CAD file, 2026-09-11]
outline/3d_structure/editable_gripper_preview/cad/12/gripper-12-exploded.step
54.5 x 83.7 x 98.9 mm
Structural_body
Source_cover
Silicone_cap
PCB_illustrative
Solder_pads_illustrative
Connector_illustrative
Connector_pins_illustrative
Sensor_01_illustrative
Sensor_02_illustrative
Sensor_03_illustrative
Sensor_04_illustrative
Sensor_05_illustrative
Sensor_06_illustrative
Sensor_07_illustrative
Sensor_08_illustrative
Sensor_09_illustrative
Sensor_10_illustrative
Sensor_11_illustrative
Sensor_12_illustrative
Wire_1_illustrative
Wire_2_illustrative
Wire_3_illustrative
Wire_4_illustrative

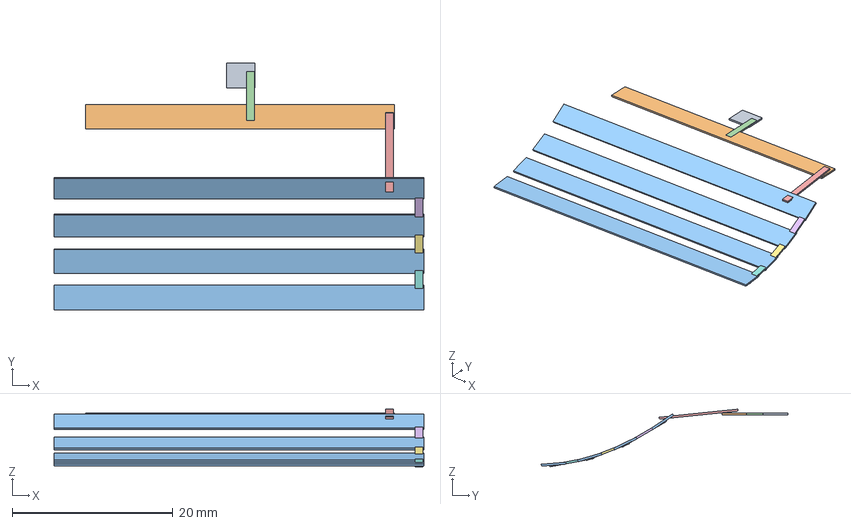
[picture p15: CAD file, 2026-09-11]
outline/3d_structure/editable_gripper_preview/cad/32/PCB_illustrative.step
46.1 x 30.7 x 7.19 mm

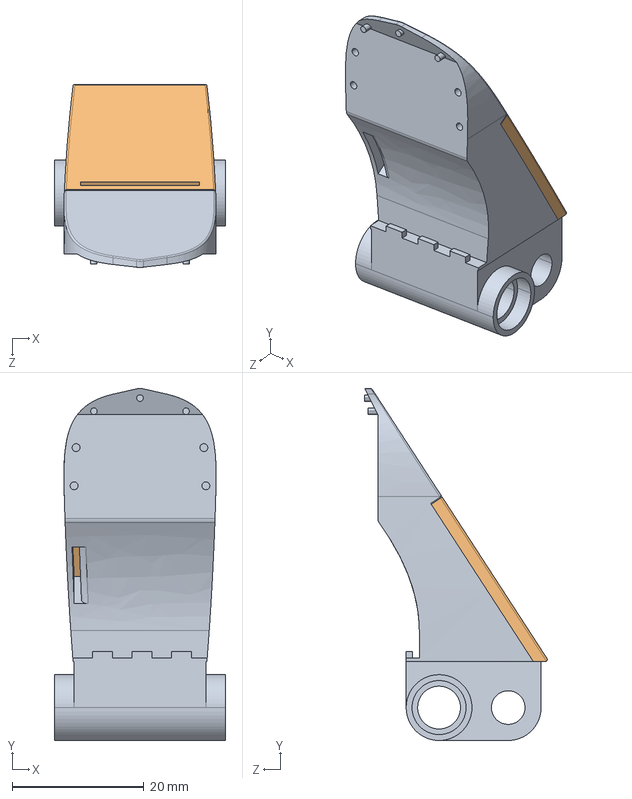
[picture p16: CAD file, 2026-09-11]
outline/3d_structure/onebody-12-jiegoujian.STEP
26.0 x 53.4 x 27.7 mm

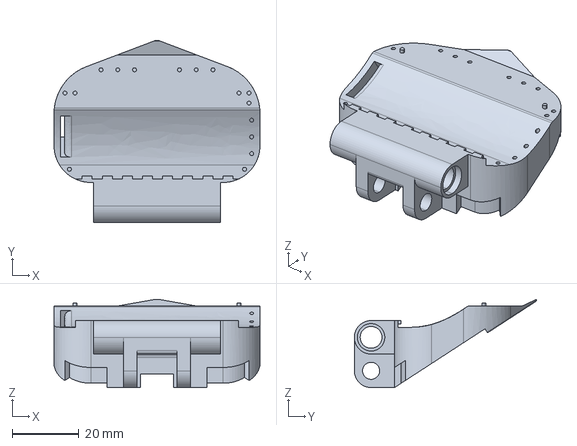
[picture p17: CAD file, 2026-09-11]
outline/3d_structure/editable_gripper_preview/cad/32/Structural_body.step
61.5 x 54.4 x 26.3 mm

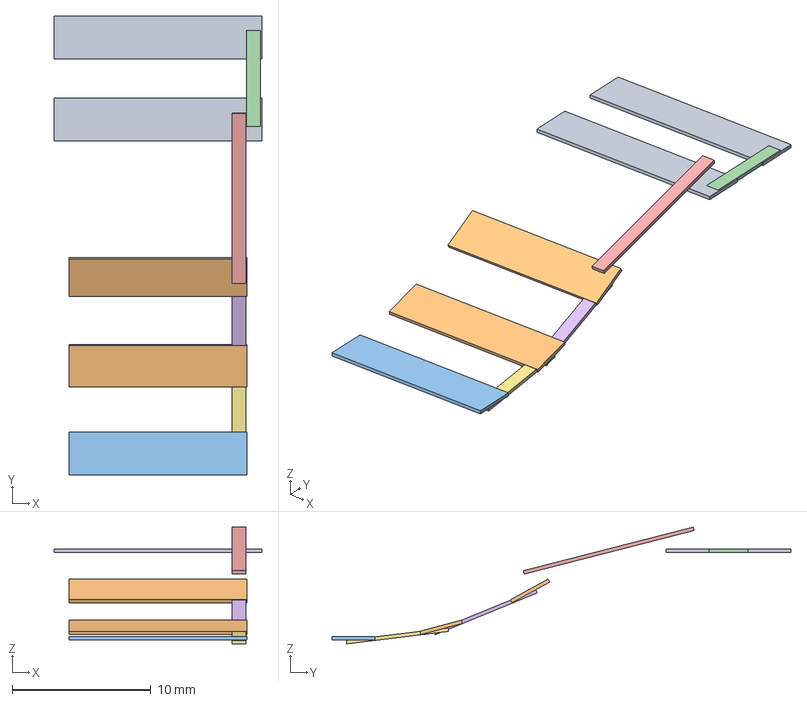
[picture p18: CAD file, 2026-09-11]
outline/3d_structure/editable_gripper_preview/cad/12/PCB_illustrative.step
15.0 x 33.0 x 8.40 mm

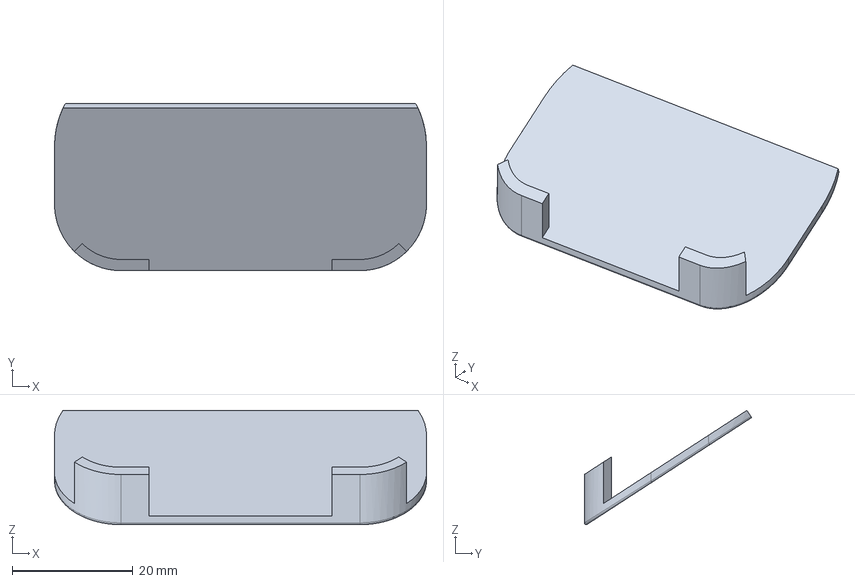
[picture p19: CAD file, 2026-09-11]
outline/3d_structure/editable_gripper_preview/cad/32/Source_cover.step
61.5 x 27.7 x 18.9 mm

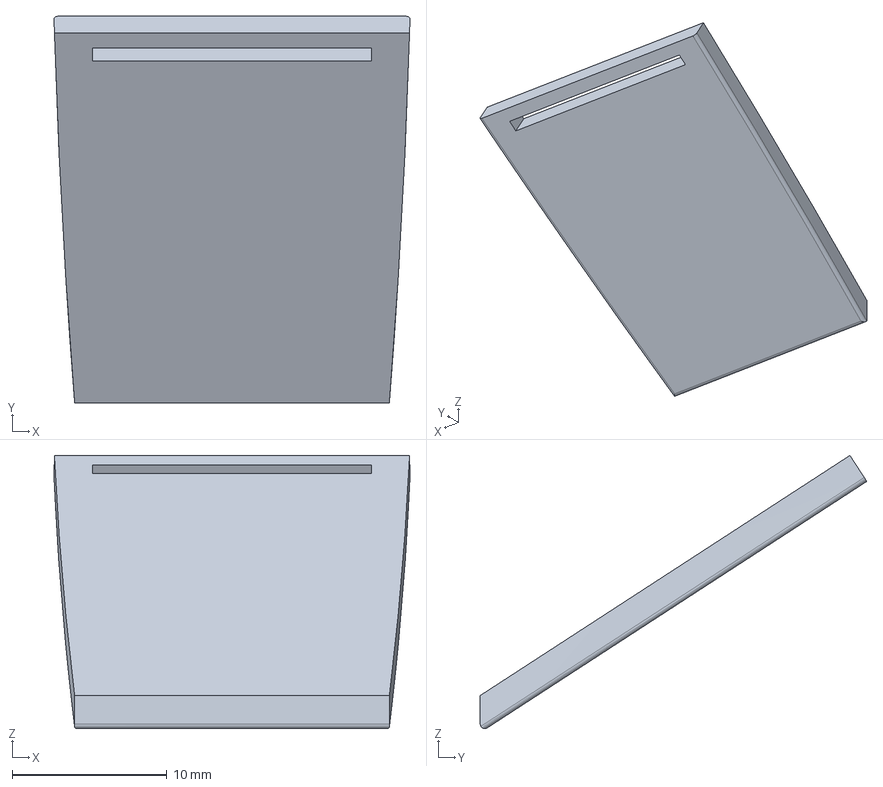
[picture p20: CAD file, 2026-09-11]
outline/3d_structure/editable_gripper_preview/cad/12/Source_cover.step
23.0 x 25.0 x 17.6 mm

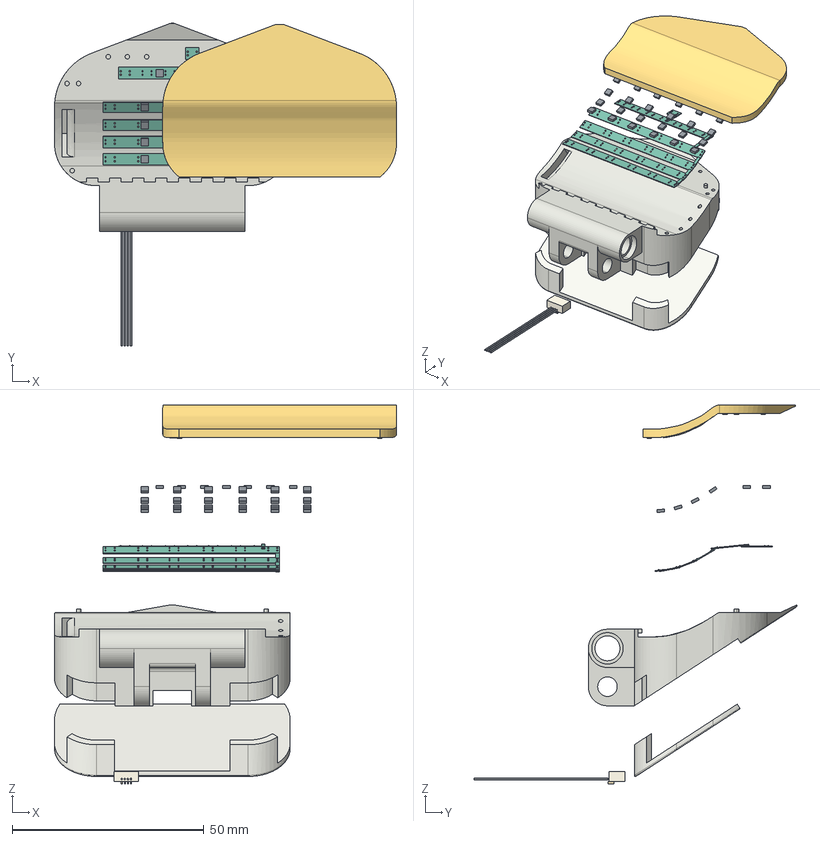
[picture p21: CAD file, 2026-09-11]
outline/3d_structure/editable_gripper_preview/cad/32/gripper-32-exploded.step
89.3 x 84.2 x 98.9 mm
Structural_body
Source_cover
Silicone_cap
PCB_illustrative
Solder_pads_illustrative
Connector_illustrative
Connector_pins_illustrative
Sensor_01_illustrative
Sensor_02_illustrative
Sensor_03_illustrative
Sensor_04_illustrative
Sensor_05_illustrative
Sensor_06_illustrative
Sensor_07_illustrative
Sensor_08_illustrative
Sensor_09_illustrative
Sensor_10_illustrative
Sensor_11_illustrative
Sensor_12_illustrative
Sensor_13_illustrative
Sensor_14_illustrative
Sensor_15_illustrative
Sensor_16_illustrative
Sensor_17_illustrative
Sensor_18_illustrative
Sensor_19_illustrative
Sensor_20_illustrative
Sensor_21_illustrative
Sensor_22_illustrative
Sensor_23_illustrative
Sensor_24_illustrative
Sensor_25_illustrative
Sensor_26_illustrative
Sensor_27_illustrative
Sensor_28_illustrative
Sensor_29_illustrative
Sensor_30_illustrative
Sensor_31_illustrative
Sensor_32_illustrative
Wire_1_illustrative
Wire_2_illustrative
Wire_3_illustrative
Wire_4_illustrative

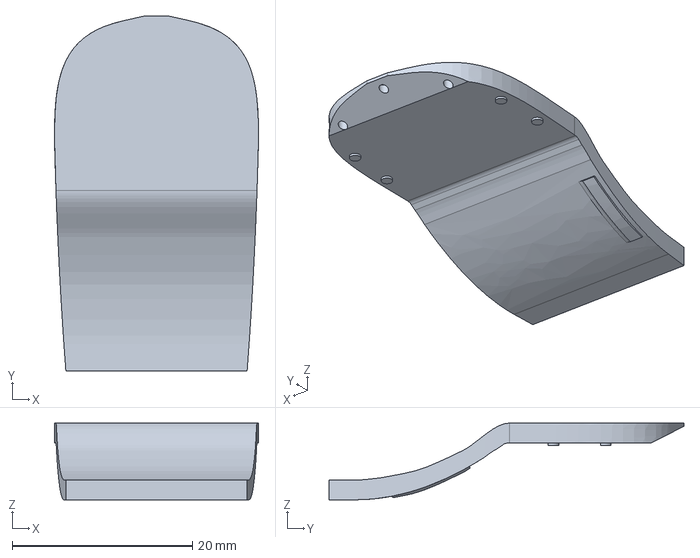
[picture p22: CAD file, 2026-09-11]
outline/3d_structure/editable_gripper_preview/cad/12/Silicone_cap.step
22.6 x 39.3 x 8.50 mm

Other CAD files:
outline/3d_structure/editable_gripper_preview/cad/12/Connector_illustrative.step
outline/3d_structure/editable_gripper_preview/cad/32/Silicone_cap.step
outline/3d_structure/editable_gripper_preview/blender/gripper-12.blend
outline/3d_structure/editable_gripper_preview/blender/gripper-32.blend

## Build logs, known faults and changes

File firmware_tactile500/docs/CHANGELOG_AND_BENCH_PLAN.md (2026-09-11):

# 固件改动与上板验收

2026-09-10。本页记录改动与分阶段验收方法；同日较早的0x21实机反馈见
[修订21说明](REVISION_21_HARDWARE_FIX.md)。下面“本轮首次烧录准备”的构建产物尚待用户上板测试。

## 本轮首次烧录准备（用户确认后）

- 明确四块板为左12、右12、左32、右32，每板500完整帧/秒；先测32点短线新版，长线为旧版。
- 线上协议保持0x21；现有identity字节已覆盖左右、通道数和长短线，没有增加额外字段。
- 保留当前采集、双缓冲和UART TC后关闭DMA的运行逻辑，新增配置层的帧率命名与帧长/串口预算编译检查。
- 用户的32点短线显示位置表已经逐项记录在[板型与通道映射](BOARD_VARIANTS_AND_CHANNEL_MAP.md)，
  MCU不重复应用网页位置换序。上位机源码未改。
- MSVC C11 /W4 /WX核心测试、六个真实编译板型的向量测试和Python独立解码的5项测试通过。
- GNU 14.3.Rel1与Keil 5.27.1 / ARMCC 5.06 update 6均重新构建六种板型。
  Keil每个目标0错误、27条相同C4008W提示（splitting LDM/STM has no benefit）；
  本轮没有为清除提示而改优化选项。GNU仍有下文列出的SDK/newlib/链接脚本警告。
- 共12份HEX逐条校验记录校验和、Flash范围、初始栈、Reset/TMR2/USART2/DMA1 Channel7向量；
  与ELF/AXF对应符号匹配，确认HEX晚于编译相关源文件。清单见build/first_flash_manifest.json（构建产物，未纳入仓库）。
- 本轮源文件备份为上一级备份目录的Tactile500_before_first_flash_20260910_192139.zip。
  本轮没有进行烧录、修改USB驱动或操作机器人；实际500Hz输出、通道读数和ADC新转换率以接下来的测量为准。

操作入口：[四板首次烧录](../先读我_四板首次烧录.md)。

## 主要修正

| 项目 | 原代码 | 当前实现 |
|---|---|---|
| 名称/入口 | I2C/I2C_TwoBoardsPolling，与实际双 SPI 触觉用途不符 | Applications/Tactile500；六种具名 Target |
| 主频/总线 | 按 16 MHz 晶振，HSE×8=128 MHz，APB1 也为 128 MHz | HSE/2×15=120 MHz；APB1=60 MHz，APB2=120 MHz |
| 帧周期 | 主循环尽快发，节拍接近串口吞吐极限 | TMR2 每 2000 us 触发发送已准备好的帧 |
| USART2 DMA | CIRCULAR，在完成回调中 DMAStop | NORMAL；DMA 完成后由 UART TC 确认真正发完，再释放缓冲 |
| 帧缓冲 | 一块全局缓冲，状态处理脆弱 | 两块独立缓冲，FREE→BUILDING→READY→SENDING→FREE |
| 启动失败 | DAL_UART_Transmit_DMA 返回值检查后有空分号 | 检查 DAL 状态及 DMA CHEN，失败记录并请求恢复 |
| 回调 | 缺少 USART2 明确隔离 | 只处理 USART2；正常完成不执行 DMAStop |
| SPI 读取 | 单字节 val 作为多字节发送指针，越界读；超时可达 100/1000 ms | 长度正确的 7 字节缓冲；单事务 100 us，单轮采集预算 1750 us |
| MISO | 复用推挽输出 | 主机 MISO 配置为输入 |
| 温度 | 未先将原始 16 位数符号扩展 | 先按 int16 解释再缩放，支持负温度 |
| 传感器有效性 | 连续读数不核对新数据 | 读取 DRDY/ERROR_CODE，fresh_mask 标记；异常保留缓存 |
| 上电标定 | 写统一系数并触发 EEPROM 编程 | 不再覆盖 0xAA 等校准系数，不触发 0x6A/0x6C 烧写 |
| 识别/诊断 | 地址和通道数，缺少长短线标识 | 六板型身份、映射版本、序号、时间、fresh、status、CRC |

主频和 APB1 调整依据：[Geehy APM32F402xB User Manual V1.1，第 31–32 页](https://global.geehy.com/uploads/tool/APM32F402xB%C2%A0User%C2%A0Manual%C2%A0V1.1.pdf)。按厂商限制，AHB/APB2 最大 120 MHz，APB1 最大 60 MHz。晶振仍按原硬件参数 16 MHz 配置，上板必须确认实际晶振。

旧单缓冲设计并不自动证明存在 DMA 改写竞争；本次修正的是已经看到的循环模式、返回值处理及指针越界等问题，不将旧数据异常归因写成实测结论。

## 当前嵌入式配置

> **2026-09-11 更新（本表以下内容为 2026-09-10 基线，部分已变更）：**
>
> | 项 | 2026-09-10 基线 | 当前 |
> |---|---|---|
> | SPI1 / SPI2 | 120 MHz/64 = 1.875 MHz；60 MHz/32 = 1.875 MHz | **120/16 = 7.5 MHz；60/8 = 7.5 MHz** |
> | 传感器滤波 | A6=0x43、A7=0x83（OSR=2048） | **A6=0x40、A7=0x80（OSR=256）** |
> | 0xA5 系统配置 | 结束时写 0x88（DAC_on=1，模拟输出模式） | **保持 0x08（DAC_on=0），改用 0x30 COMMAND 触发单次转换** |
> | 采集时序 | 每帧盲读寄存器 | **流水线：读上一轮结果后立即触发下一轮** |
>
> 变更原因、datasheet 依据与验证方法见
> [DRDY 修复与 v3 自愈记录](DRDY修复与v3自愈记录.md)。
> SPI 提速依据 NSA2302 datasheet Rev1.2 Table 7.2（f_sclk 上限 10 MHz）。

| 模块 | 参数 |
|---|---|
| MCU | APM32F402RB，Cortex-M4F，Flash 128 KB，RAM 32 KB |
| 时钟 | HSE=16 MHz，PLL=/2×15，SYSCLK/HCLK=120 MHz，PCLK1=60 MHz，PCLK2=120 MHz |
| TMR2 | APB1 定时器倍频后 120 MHz；PSC=119，AUTORLD=1999，1 MHz 计数，500 Hz 更新 |
| UART2 | PA2 TX，921600，8N1，无流控、无 RX 命令通路 |
| UART2 TX DMA | DMA1 Channel7，NORMAL，内存递增、外设不增、字节对齐、HIGH 优先级 |
| NVIC | 分组 4；TMR2、USART2、DMA1 Channel7 的抢占优先级均为 1；不相互抢占 |
| 时基 | SysTick 1 ms；DWT 周期计数扩展为 uint32 微秒时间 |
| SPI1 | PA5/PA6/PA7=SCK/MISO/MOSI，120 MHz/64=1.875 MHz ⚠️**已变更，见上** |
| SPI2 | PB13/PB14/PB15=SCK/MISO/MOSI，60 MHz/32=1.875 MHz ⚠️**已变更，见上** |
| SPI 模式 | Mode 0，8 bit，MSB first，软件片选；MISO 输入 |
| 传感器滤波 | A6=0x43、A7=0x83，沿用原 OSR=2048 设置 |
| 传感器启动 | 软复位，启动时等待 1 s，写工作配置并读回接口寄存器；不写 EEPROM |
| 收发控制 | PA0/PA1 初始化低，开始连续发送前拉高，沿用原板的 RS485 控制电平 |
| 调试口 | 关闭 JTAG 以释放 PB3/PB4/PA15；保留 SWD，禁止把这些触觉 CS 当空闲调试引脚 |
| 栈/堆 | GNU 和 Keil 均配置 2048 B 栈、512 B 堆；主循环不动态分配帧 |

## 为什么用两个缓冲区

主循环只写 FREE 缓冲区，读完传感器并算完 CRC 后标为 READY。TMR2 中断只选择本时隙 READY 帧启动 DMA；另一个缓冲区可以同时准备下一帧。DMA 使用的 SENDING 缓冲区在 UART TC 前不改写。

传输尚未结束时不会覆盖或叠加发送。定时启动迟到超过 20 us 时跳过该时隙；序号照常增加，下一帧能看到缺口。活动传输跨过约 4 ms 仍未结束时，请求主循环停止异常传输、复位驱动发送状态，再继续后面的周期。异常恢复可能形成残帧；上位机通过 CRC 和同步头恢复。

中断和主循环共享状态只在极短临界区内修改，SPI 采集、CRC 运算和等待均不放在临界区。DMA 半传输中断在每次启动后关闭，以减少无用中断。无帧队列积压，不做“赶进度”突发补发。

## 带宽和采样限制

921600、8N1 每字节占 10 个串口位：

| 规模 | 字节/帧 | 按标称波特率发送时间 | 2 ms 周期内剩余 |
|---|---:|---:|---:|
| 12 点 | 80 | 868.06 us | 1131.94 us |
| 32 点 | 180 | 1953.125 us | 46.875 us |

60 MHz PCLK1 下驱动的整数波特率分频值为 65，实际标称约 923076.9 baud（比请求值高约 0.16%），32 点线占用约 1950 us。实测以逻辑分析仪为准，主机仍设置 921600。

32 点留给中断延迟和下次启动的余量很小。若真实 UART 波形存在超期，先查时钟、SPI 用时、中断和硬件链路；不要在上位机通过丢包/插值掩盖。协议已经接近当前波特率能容纳的大小，新增字段前必须重新核算。

本轮没有调整 NSA2302 模拟采样滤波，不能把 500 Hz 发包直接等同于每个通道 500 Hz 新测量。如果 fresh 比例不足而链路稳定，应另做 DRDY 周期与 OSR/噪声测试后决定参数；也不能通过把 fresh 位强制置 1 解决。旧固件已写入 EEPROM 的内容不会因这次停止写入而自动恢复，若原始标定已丢失，需要原备份或重新标定。

## 烧录顺序（现场执行）

1. 确认实际板型、主芯片丝印、16 MHz 晶振、供电和烧录器型号；仅连接一块触觉板。左右及长/短线必须与 Target 对应。
2. 安装用户目录中的 MDK527.EXE，再安装 Geehy.APM32F4xx_DFP.1.0.7.pack。或者使用已安装且支持 APM32F402RB 的烧录工具直接下载现成 GNU HEX。无需运行其他未必相关的安装程序。
3. 打开 `Project/MDK/Tactile500.uvprojx`，选择表中正确的 Target，Rebuild。输出 `build/keil/<Target后缀>/Tactile500_<Target后缀>.hex`。如提示 Arm Compiler 缺失，按实际已安装编译器选择；不要忽略错误使用旧 HEX。
4. 在 Debug/Utilities 中按实际探针选择驱动、SWD 接口、低速起步（例如 1 MHz）；查到正确芯片后再下载。工程未固定原作者的探针序列号。SWDIO/SWCLK/GND/参考电压按板子丝印接，不凭颜色猜。
5. Flash 算法应为支持包的 `APM32F402_128.FLM`；Flash 范围从 0x08000000 起共 0x20000 字节。HEX 自带地址；BIN 才需要手动指定起始地址。
6. 使用一种构建产物烧录并执行 Verify。结束调试单步与断点，让 MCU 自由运行；重新上电约 1 s 初始化后开始数据流。记录具体固件文件和 build_manifest.json 哈希。

## 分阶段验收

| 阶段 | 操作 | 通过条件/记录 |
|---|---|---|
| A：只读确认 | 看芯片、晶振、供电、探针识别 | 板型和参数与工程一致，记录照片/型号 |
| B：首次 10–30 秒 | 一块板烧录并核验，逻辑分析仪测 PA2 与 SPI | UART 可按 921600/8N1 解码，帧头间隔约 2 ms；SPI 两路 7.5 MHz（2026-09-11 起；此前 1.875 MHz）；没有持续初始化/SPI 错误 |
| C：1 分钟协议 | 持续收取 UART 字节并保存，每个设备独立文件 | CRC 合法；长度 80/180；身份与实物一致；sequence 连续且无重复；timestamp 增量约 2000 us |
| D：通道映射 | 无载荷静置，再逐点按压 12 或 32 点 | 位置与通道一一对应，左右正确，长/短线未二次换序；检查负温度/无效值解码 |
| E：30 分钟稳定性 | 一块板连续采集，随后再测多板同时接入 | 期望约 900000 帧/板；稳态窗口 CRC 错误=0、内部缺口=0、重复=0；PC 实时时钟计算帧率并记录偏差 |
| F：新数据率 | 逐通道统计 fresh_mask 比例，并观测 DRDY/采集波形 | 分别报告各通道“收到的帧率”和“有效新数据率”；若不是 500 新测量/s，保留原始证据再调整模拟参数。**2026-09-11 起 fresh_mask 才真正可用**：此前固件处于模拟输出模式，DRDY 恒为 0（见上文更新说明）；先读调试器 `g_tactile_diag.prime_conversion_us` 得到真实转换时间 |
| G：错误恢复 | 稳态通过后再做可控断连/读超时试验 | 不永久卡死，恢复后能重同步；状态/序号能揭示故障；先停电再改接线 |

开始/结束截断的半帧应单独记录，不混入稳态 CRC 错误统计。30 分钟总数需考虑 PC 计时窗口边界和晶振误差；同时要求窗口内 sequence 没有缺口，不能只看约 500 的平均值。主机一次 USB 读取的时间间隔不是 UART 发包间隔。

离线报告命令：

```powershell
python tools/protocol_v2.py capture.bin --output capture_report.json
```

该报告输出有效帧数、错候选头数、丢弃字节、尾部半帧、序号缺口/重复/回绕后的速率、各通道 fresh 比例和 status 计数。它的速率使用 MCU 采集时间，物理 500 Hz 必须另配 PA2 波形或 PC 单调时间记录。每个 USB 设备各存一份，避免同型两板的序号相互混淆。

调试器可只读观察 `g_tactile_stream.sent_frames`、`missed_slots`、`sweep_overruns`、`tx_errors`、`latched_status`。暂停 CPU 会人为破坏时序；看完后重新上电再做正式计数。

## 已完成的离线验证与边界

- Arm GNU Toolchain 14.3.Rel1：六种 Cortex-M4F 固件构建成功，输出 HEX/BIN/ELF/MAP。
- MSVC C11 /W4 /WX：CRC 标准向量、帧长/边界、符号数、双缓冲归属、启动失败、忙状态恢复、错过周期及 uint32 序号回绕测试通过。
- Python 标准库独立解码 C 生成的六种帧：身份、符号数、小端、CRC、任意分包、坏帧重同步、序号/时间回绕和缺口统计通过。
- 早期仅静态核对Keil工程；本轮已追加六种Target的实际Keil构建，结果见本页顶部。
- GNU 日志仍有原厂驱动的未使用参数警告，以及 newlib nosys 和原链接脚本 RWX 段警告；新增应用及配置代码采用 -Werror 编译。未修改原厂驱动来掩盖警告。

以上不能代替示波器、逻辑分析仪或实际 USB 接收验证。现场结果填写：日期、板型、固件哈希、探针、供电、USB 桥 VID/PID、驱动、串口时序、有效帧数、CRC/缺口/重复、每通道 fresh、按压映射、异常日志。

DeepSeek 上位机待作者完成后再审阅，当前未改动。届时重点检查 V2 兼容性、Windows PyUSB 驱动和打包、持续读循环、跨包重同步、六种身份、单设备独立统计，以及 GUI 显示刷新与采集分离。

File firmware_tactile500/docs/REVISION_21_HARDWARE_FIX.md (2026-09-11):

# 固件修订 0x21：首次实机反馈后的修正

初版实机结果为 V2 0x20、约125帧/秒、序号每次跳4、TX_BUSY锁存和全部启动哨兵。
这说明编译通过没有代替实物验收。

1. APM32F402普通DMA计数归零后CHEN仍保持置位，所附DAL没有在下次重装计数前关通道。
   现于USART2的UART TC完成回调关闭DMA通道，确认末尾停止位发完后再释放缓冲区。
   这样下一帧可重装计数，不再等待超时恢复，也不提前截断尾部。
2. 配置NSA2302时先A5=08关闭DAC模式，设置A6/A7后最后A5=88启动。对接口和A5/A6/A7
   精确读回校验；保留原OSR/滤波和EEPROM标定，不重新烧写EEPROM。
3. DRDY=0时仍读取寄存器，避免一直输出启动哨兵；仅DRDY=1且读取成功时设置fresh位。
4. 版本字节改为0x21，六个GNU目标重建；用户通过Keil重建并烧录了左12和左32短线。

重新插回G1后收到身份08/0E、修订21。交换Hub口不影响按协议识别角色。两板恢复到约500
帧/秒，温度/压力有可读值，未出现SPI/初始化/TX错误位。同步PyUSB读取仍出现少量丢字节；
上位机用PyUSB的libusb1后端预排队异步请求后，30秒短测两板均没有序号缺口。
后续持续测试见相邻gpt6上位机项目的reports与验收报告。

当前DAC模式DRDY实测全0，不能据此宣称每通道500Hz新ADC转换。尚无示波器边沿、ADC
带宽/噪声测量，固件仍为TX连续输出，未增加共享触发或接收同步启动命令。

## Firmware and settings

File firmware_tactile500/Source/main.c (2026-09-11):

/* *  Copyright (C) 2024-2025 Geehy Semiconductor
 *
 *  You may not use this file except in compliance with the
 *  GEEHY COPYRIGHT NOTICE (GEEHY SOFTWARE PACKAGE LICENSE).
 *
 *  The program is only for reference, which is distributed in the hope
 *  that it will be useful and instructional for customers to develop
 *  their software. Unless required by applicable law or agreed to in
 *  writing, the program is distributed on an "AS IS" BASIS, WITHOUT
 *  ANY WARRANTY OR CONDITIONS OF ANY KIND, either express or implied.
 *  See the GEEHY SOFTWARE PACKAGE LICENSE for the governing permissions
 *  and limitations under the License.
 */
/**
 * @file main.c
 * @brief Tactile500: APM32F402, dual SPI, 500 Hz UART DMA streaming.
 *
 * Based on the supplied Geehy example; vendor license terms above apply.
 */
#include "main.h"
#include "apm32f4xx_device_cfg.h"
#include "apm32f4xx_usart_cfg.h"
#include "tactile_config.h"
#include "tactile_protocol.h"
#include "tactile_sensor.h"
#include "tactile_stream.h"
#include "tactile_time.h"

/* 可在调试器中查看累计帧数、漏发槽位、超时和DMA错误。 */
TactileStream g_tactile_stream;
static TactileSample sample;

static void RecoverUartIfNeeded(void)
{
    uint32_t primask;
    DAL_StatusTypeDef status;

    primask = TactileCritical_Enter();
    if (g_tactile_stream.recover_requested == 0U)
    {
        TactileCritical_Exit(primask);
        return;
    }
    g_tactile_stream.recovering = 1U;
    TactileCritical_Exit(primask);

    /* 恢复在主循环执行。SysTick和500Hz定时器继续运行，不在ISR里等待。 */
    status = DAL_UART_AbortTransmit(&huart2);
    primask = TactileCritical_Enter();
    if (status == DAL_OK)
    {
        TactileStream_RecoveryComplete(&g_tactile_stream);
    }
    else
    {
        TactileStream_TxError(&g_tactile_stream);
        g_tactile_stream.recovering = 0U;
    }
    TactileCritical_Exit(primask);
}

static void BuildNextFrame(void)
{
    uint32_t sequence;
    uint32_t primask;
    uint8_t status;
    size_t length;
    int slot;

    primask = TactileCritical_Enter();
    slot = TactileStream_Claim(&g_tactile_stream, &sequence);
    TactileCritical_Exit(primask);
    if (slot < 0)
    {
        return;
    }

    TactileSensor_Collect(&sample);
    primask = TactileCritical_Enter();
    if ((sample.status & TACTILE_STATUS_SWEEP_LATE) != 0U)
    {
        g_tactile_stream.latched_status |= TACTILE_STATUS_SWEEP_LATE;
        ++g_tactile_stream.sweep_overruns;
    }
    status = (uint8_t)(sample.status | g_tactile_stream.latched_status);
    TactileCritical_Exit(primask);

    length = TactileProtocol_Encode(
        g_tactile_stream.frame[slot], TACTILE_FRAME_MAX_BYTES,
        TACTILE_WIRE_VERSION, TACTILE_IDENTITY, status, sequence,
        sample.sample_time_us, sample.fresh_mask, sample.temperature,
        sample.pressure, TACTILE_CHANNEL_COUNT);

    primask = TactileCritical_Enter();
    (void)TactileStream_Publish(&g_tactile_stream, slot, length);
    TactileCritical_Exit(primask);
}

/* 仅从TMR2中断调用。这里只启动已备好的帧，不做SPI采集或CRC运算。 */
void TactileApp_OnTimer(void)
{
    uint32_t lateness_us;
    uint32_t periods;
    DAL_StatusTypeDef status;
    int slot;

    periods = TactileTimer_ElapsedPeriods(&lateness_us);
    slot = TactileStream_OnTick(&g_tactile_stream, periods,
                               lateness_us <= TACTILE_TX_MAX_LATENESS_US);
    if (slot < 0)
    {
        return;
    }
    status = DAL_UART_Transmit_DMA(&huart2,
                                   g_tactile_stream.frame[slot],
                                   (uint16_t)g_tactile_stream.length[slot]);
    if (status != DAL_OK ||
        (hdma_usart2_tx.Instance->CHCFG & DMA_CHCFG_CHEN) == 0U)
    {
        TactileStream_TxStartFailed(&g_tactile_stream);
        return;
    }
    TactileStream_TxStarted(&g_tactile_stream);
    __DAL_DMA_DISABLE_IT(&hdma_usart2_tx, DMA_IT_HT);
}

void DAL_UART_TxCpltCallback(UART_HandleTypeDef *uart)
{
    if (uart->Instance == USART2)
    {
        /* APM32F402 的普通 DMA 计数归零后 CHEN 仍置位。
         * 本版 DAL_DMA_Start_IT 未先关通道，不能在 CHEN=1 时重装计数。
         * UART TC 已确认末尾停止位发送完毕，此处关通道后才释放缓冲区。 */
        __DAL_DMA_DISABLE(&hdma_usart2_tx);
        TactileStream_TxComplete(&g_tactile_stream);
    }
}

void DAL_UART_ErrorCallback(UART_HandleTypeDef *uart)
{
    if (uart->Instance == USART2)
    {
        TactileStream_TxError(&g_tactile_stream);
    }
}

int main(void)
{
    DAL_DeviceConfig();
    TactileTime_Init();
    TactileSensor_Init();
    TactileStream_Init(&g_tactile_stream);

    /* 连续上报模式：沿用原板PA0/PA1的485发送电平，不接收旧校准命令。 */
    DAL_GPIO_WritePin(GPIOA, GPIO_PIN_0 | GPIO_PIN_1, GPIO_PIN_SET);
    TactileTimer_Start();
    for (;;)
    {
        RecoverUartIfNeeded();
        BuildNextFrame();
    }
}

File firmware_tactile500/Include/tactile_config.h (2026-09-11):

#ifndef TACTILE_CONFIG_H
#define TACTILE_CONFIG_H

#include <stdint.h>
#include "tactile_protocol.h"

/* 四块板：左12、右12、左32、右32；每块板独立接一只CH340。
 * 32点短线=新版（旧代码NEW_HARDWARE=1），长线=旧版（=0）。
 * 在Keil的Target下拉框选择板型，不再另外修改NEW_HARDWARE。
 * 原始通道顺序保持不变；网页位置映射见docs/BOARD_VARIANTS_AND_CHANNEL_MAP.md。 */
#define TACTILE_LEFT_FINGERS12       1
#define TACTILE_RIGHT_FINGERS12      2
#define TACTILE_LEFT_PALM32_LONG     3
#define TACTILE_RIGHT_PALM32_LONG    4
#define TACTILE_LEFT_PALM32_SHORT    5
#define TACTILE_RIGHT_PALM32_SHORT   6

#ifndef TACTILE_PROFILE
#define TACTILE_PROFILE TACTILE_RIGHT_PALM32_SHORT
#endif

#define TACTILE_CABLE_NONE   0U
#define TACTILE_CABLE_LONG   1U
#define TACTILE_CABLE_SHORT  2U

#if TACTILE_PROFILE == TACTILE_LEFT_FINGERS12
#define TACTILE_HAND_ID       1U
#define TACTILE_CHANNEL_COUNT 12U
#define TACTILE_CABLE_VARIANT TACTILE_CABLE_NONE
#elif TACTILE_PROFILE == TACTILE_RIGHT_FINGERS12
#define TACTILE_HAND_ID       2U
#define TACTILE_CHANNEL_COUNT 12U
#define TACTILE_CABLE_VARIANT TACTILE_CABLE_NONE
#elif TACTILE_PROFILE == TACTILE_LEFT_PALM32_LONG
#define TACTILE_HAND_ID       1U
#define TACTILE_CHANNEL_COUNT 32U
#define TACTILE_CABLE_VARIANT TACTILE_CABLE_LONG
#elif TACTILE_PROFILE == TACTILE_RIGHT_PALM32_LONG
#define TACTILE_HAND_ID       2U
#define TACTILE_CHANNEL_COUNT 32U
#define TACTILE_CABLE_VARIANT TACTILE_CABLE_LONG
#elif TACTILE_PROFILE == TACTILE_LEFT_PALM32_SHORT
#define TACTILE_HAND_ID       1U
#define TACTILE_CHANNEL_COUNT 32U
#define TACTILE_CABLE_VARIANT TACTILE_CABLE_SHORT
#elif TACTILE_PROFILE == TACTILE_RIGHT_PALM32_SHORT
#define TACTILE_HAND_ID       2U
#define TACTILE_CHANNEL_COUNT 32U
#define TACTILE_CABLE_VARIANT TACTILE_CABLE_SHORT
#else
#error "TACTILE_PROFILE must select one of the six supported boards"
#endif

/* 第一阶段验收的是整帧发送率；这不代表ADC每秒完成500次新转换。 */
#define TACTILE_FRAME_RATE_HZ        500U
#define TACTILE_SAMPLE_RATE_HZ       TACTILE_FRAME_RATE_HZ /* 旧宏名兼容 */
#define TACTILE_PERIOD_US            (1000000U / TACTILE_FRAME_RATE_HZ)
#define TACTILE_UART_BAUDRATE        921600U
#define TACTILE_MAPPING_REVISION     1U
#define TACTILE_WIRE_VERSION         0x21U /* 协议主版本 2，固件修订 1。 */

/* 2026-09-11：SPI 从 1.875MHz 提到 3.75MHz。
 * 依据 NSA2302 datasheet Rev1.2 Table 7.2：f_sclk 上限 10MHz（负载25pF）。
 * 提速原因：改为命令驱动单次转换后每帧要额外写 0x30 触发寄存器，
 * 每帧SPI字节数 320 -> 416。1.875MHz 需 1.78ms，超过 1.75ms 扫描预算；
 * 3.75MHz 只需 0.89ms，留出约一半余量。
 *
 * 实测记录：先按 7.5MHz 试过一版，初始化回读校验在 SPI1 侧通道
 * （channel < COUNT/2）成片失败，判定为 32 片并联总线在该速率下
 * 信号完整性不足。降到 3.75MHz（仍为原速 2 倍）后应消除。
 * 若仍失败，看 g_tactile_diag.init_a5_rb[] / init_fail_mask 定位。 */
#define TACTILE_SPI1_PRESCALER        SPI_BAUDRATEPRESCALER_32 /* 120/32 = 3.75MHz */
#define TACTILE_SPI2_PRESCALER        SPI_BAUDRATEPRESCALER_16 /*  60/16 = 3.75MHz */
#define TACTILE_SENSOR_PCH_CONFIG    0x40U /* 压力增益32倍，OSR=256 */
#define TACTILE_SENSOR_TCH_CONFIG    0x80U /* 内部温度，增益1倍，OSR=256 */

/* NSA2302 系统配置寄存器 0xA5，bit7 = DAC_on（1 = Enable voltage output mode）。
 * 原固件写 0x88 置 DAC_on=1，芯片进入 datasheet 6.3 节的 analog output mode：
 * 自主执行"64次压力 + 1次温度"转换，且手册明确 "no matter what 'CMD'
 * registers contents"。该模式不属于 6.5.1 节命令驱动的四种工作模式，
 * 因此 INT/DRDY 不置位 —— 这正是 fresh_mask 恒为 0 的根因。
 * 现保持 DAC_on=0：0x08 仅保留 bit3 Regulator_sel=1（VEXT 仍为 2.4V，
 * 与原来一致，传感器激励与读数标度不变），其余位为 0。 */
#define TACTILE_SENSOR_SYS_CONFIG    0x08U

/* NSA2302 COMMAND 寄存器 0x30
 * bit3   = Sco：1 = 启动转换，转换结束自动回 0（睡眠模式除外）
 * bit2:0 = CMD：000单次温度 001单次传感器 010组合(温度+传感器) 011睡眠周期 */
#define TACTILE_SENSOR_CMD_REG       0x30U
#define TACTILE_SENSOR_CMD_SENSOR    0x09U /* Sco=1, CMD=001 单次传感器转换 */
#define TACTILE_SENSOR_CMD_COMBINED  0x0AU /* Sco=1, CMD=010 组合转换 */

/* 温度刷新周期（以帧计）。单次传感器转换不更新温度寄存器，
 * 因此每 N 帧改用一次组合转换刷新温度。500Hz 下 64 帧 = 128ms。 */
#define TACTILE_SENSOR_TEMP_EVERY    64U

/* 连续 N 帧 DRDY 未就绪则补触发一次，防止触发丢失后通道永久卡死。 */
#define TACTILE_SENSOR_MISS_LIMIT    3U

/* 运行中自愈（2026-09-11 v3 新增）。
 * 背景：板载 EEPROM 里 0xA5 = 0x88（模拟输出模式，早期固件烧入）。
 * 上电时 EEPROM 自动加载，固件再写 0xA5 = 0x08 切到命令模式。
 * 若该写入未生效，芯片保持模拟输出模式，此时写 0x30 触发命令会被
 * 忽略（datasheet 6.3 节 "no matter what CMD registers contents"），
 * DRDY 永不置位 → fresh_mask 恒 0。
 * 因此：某通道连续 N 帧 DRDY=0 时，整套重写配置并重新触发。 */
#define TACTILE_RECOVER_AFTER_MISSES   4U
/* 每帧最多恢复几个通道，避免恢复写入挤占 1750us 扫描预算。 */
#define TACTILE_RECOVER_MAX_PER_FRAME  8U

/* 上电首轮等待所有通道转换完成的上限（微秒）。
 * 该轮轮询会实测出真实的"触发->DRDY置位"耗时，存入诊断量。 */
#define TACTILE_SENSOR_PRIME_TIMEOUT_US  20000U

#define TACTILE_SPI_TRANSACTION_US   100U
#define TACTILE_SWEEP_BUDGET_US      1750U
#define TACTILE_TX_MAX_LATENESS_US   20U

/* 根据实际板型核算8N1串口预算，新增字段时编译器会阻止超出2ms的配置。
 * 按请求波特率向上取整：12点869us，32点1954us。
 * 该检查不替代晶振、UART边沿和实际中断耗时测量。 */
#define TACTILE_FRAME_BYTES          (TACTILE_FRAME_OVERHEAD + 5U * TACTILE_CHANNEL_COUNT)
#define TACTILE_UART_BITS_PER_BYTE   10U
#define TACTILE_UART_FRAME_TIME_US   ((TACTILE_FRAME_BYTES * TACTILE_UART_BITS_PER_BYTE * \
                                      1000000U + TACTILE_UART_BAUDRATE - 1U) / \
                                     TACTILE_UART_BAUDRATE)
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

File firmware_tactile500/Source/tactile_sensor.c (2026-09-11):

#include "tactile_sensor.h"
#include "tactile_protocol.h"
#include "tactile_time.h"
#include "apm32f4xx_spi_cfg.h"
#include <string.h>

#define NSA_REG_INTERFACE    0x00U
#define NSA_REG_DATA_READY   0x02U
#define NSA_REG_TEMP_LSB     0x0AU
#define NSA_DATA_READY       0x01U
#define NSA_SENSOR_ERRORS    0xFCU

static int16_t last_temperature[TACTILE_CHANNEL_COUNT];
static int32_t last_pressure[TACTILE_CHANNEL_COUNT];
static uint32_t init_failed_mask;

/* 流水线状态。trigger_time_us 记录每通道上次触发时刻，用于测量转换耗时。 */
static uint32_t trigger_time_us[TACTILE_CHANNEL_COUNT];
static uint8_t miss_count[TACTILE_CHANNEL_COUNT];
static uint32_t frame_counter;

/* 调试器可观察的诊断量。 */
volatile TactileDiag g_tactile_diag;

static int SpiTransfer(uint8_t channel, const uint8_t *tx,
                       uint8_t *rx, uint8_t length)
{
    SPI_TypeDef *spi;
    TactileChipSelect cs;
    uint32_t started;
    uint32_t original_ctrl;
    uint8_t index;
    volatile uint32_t discard;

    if (channel >= TACTILE_CHANNEL_COUNT || tx == NULL || rx == NULL)
    {
        return 0;
    }
    spi = channel < TACTILE_CHANNEL_COUNT / 2U ? SPI1 : SPI2;
    cs = TactileChannels_Get(channel);
    original_ctrl = spi->CTRL1;
    started = TactileTime_NowUs();
    DAL_GPIO_WritePin(cs.port, cs.pin, GPIO_PIN_RESET);

    /* 每发一字节收一字节，既提供时钟，也避免接收溢出。 */
    for (index = 0U; index < length; ++index)
    {
        while ((spi->STS & SPI_STS_TXBEFLG) == 0U)
        {
            if ((uint32_t)(TactileTime_NowUs() - started) >=
                TACTILE_SPI_TRANSACTION_US)
            {
                goto failed;
            }
        }
        *(__IO uint8_t *)&spi->DATA = tx[index];
        while ((spi->STS & SPI_STS_RXBNEFLG) == 0U)
        {
            if ((uint32_t)(TactileTime_NowUs() - started) >=
                TACTILE_SPI_TRANSACTION_US)
            {
                goto failed;
            }
        }
        rx[index] = (uint8_t)spi->DATA;
    }
    while ((spi->STS & SPI_STS_BSYFLG) != 0U)
    {
        if ((uint32_t)(TactileTime_NowUs() - started) >=
            TACTILE_SPI_TRANSACTION_US)
        {
            goto failed;
        }
    }
    if ((spi->STS & (SPI_STS_OVRFLG | SPI_STS_MEFLG)) != 0U)
    {
        goto failed;
    }
    DAL_GPIO_WritePin(cs.port, cs.pin, GPIO_PIN_SET);
    return 1;

failed:
    DAL_GPIO_WritePin(cs.port, cs.pin, GPIO_PIN_SET);
    spi->CTRL1 &= ~SPI_CTRL1_SPIEN;
    discard = spi->DATA;
    discard = spi->STS;
    (void)discard;
    spi->CTRL1 = original_ctrl; /* 恢复主机配置与 SPIEN，下一周期可重试。 */
    return 0;
}

static int WriteRegister(uint8_t channel, uint8_t address, uint8_t value)
{
    uint8_t tx[3] = {0x00U, 0U, 0U};
    uint8_t rx[3];
    tx[1] = address;
    tx[2] = value;
    return SpiTransfer(channel, tx, rx, 3U);
}

static int ReadRegister(uint8_t channel, uint8_t address, uint8_t *value)
{
    uint8_t tx[3] = {0x80U, 0U, 0xFFU};
    uint8_t rx[3];
    tx[1] = address;
    if (!SpiTransfer(channel, tx, rx, 3U))
    {
        return 0;
    }
    *value = rx[2];
    return 1;
}

static int ReadMeasurement(uint8_t channel, int16_t *temperature,
                           int32_t *pressure)
{
    /* 0xE0: 连续读取（W1:W0=11）；MSB-first 模式从 0x0A 向 0x06 递减地址。
     * 取 0x0A/0x09 为温度、0x08/0x07/0x06 为压力。 */
    const uint8_t tx[7] = {0xE0U, NSA_REG_TEMP_LSB,
                           0xFFU, 0xFFU, 0xFFU, 0xFFU, 0xFFU};
    uint8_t rx[7];
    uint16_t temp_bits;
    int32_t raw_pressure;
    uint32_t pressure_bits;
    if (!SpiTransfer(channel, tx, rx, 7U))
    {
        return 0;
    }
    temp_bits = (uint16_t)((uint16_t)rx[2] | ((uint16_t)rx[3] << 8));
    *temperature = (int16_t)(((int32_t)(int16_t)temp_bits * 10) / 256);
    pressure_bits = (uint32_t)rx[4] | ((uint32_t)rx[5] << 8) |
                    ((uint32_t)rx[6] << 16);
    raw_pressure = (int32_t)(pressure_bits & 0x7FFFFFU) -
                   (int32_t)(pressure_bits & 0x800000U);
    /* 原固件的0.1125系数，改为精确9/80；单位仍需实物标定确认。 */
    *pressure = (raw_pressure * 9) / 80;
    return 1;
}

/* 写整套通道配置。初始化与运行中自愈共用同一份。 */
static int ApplyChannelConfig(uint8_t channel)
{
    int ok = WriteRegister(channel, NSA_REG_INTERFACE, 0x81U);
    ok &= WriteRegister(channel, 0xA4U, 0x00U);
    ok &= WriteRegister(channel, 0xA5U, TACTILE_SENSOR_SYS_CONFIG);
    ok &= WriteRegister(channel, 0xA6U, TACTILE_SENSOR_PCH_CONFIG);
    ok &= WriteRegister(channel, 0xA7U, TACTILE_SENSOR_TCH_CONFIG);
    return ok;
}

/* 触发一次转换并记录时刻。不等待：转换在帧间隔里自己跑完。 */
static int TriggerConversion(uint8_t channel, uint8_t command)
{
    if (channel >= TACTILE_CHANNEL_COUNT)
    {
        return 0;
    }
    if (!WriteRegister(channel, TACTILE_SENSOR_CMD_REG, command))
    {
        return 0;
    }
    trigger_time_us[channel] = TactileTime_NowUs();
    return 1;
}

/* 上电首轮：触发全部通道并轮询到就绪。
 * 这一次轮询是唯一能测得"真实转换时间"的机会（之后 DRDY 读取都晚于转换结束）。
 * v3 起对校验失败的通道也一并触发，给它们自愈机会。 */
static void PrimeFirstConversion(void)
{
    uint8_t channel;
    uint8_t done[TACTILE_CHANNEL_COUNT];
    uint32_t started;
    uint32_t remaining = 0U;

    for (channel = 0U; channel < TACTILE_CHANNEL_COUNT; ++channel)
    {
        done[channel] = 0U;
        ++remaining;
        (void)TriggerConversion(channel, TACTILE_SENSOR_CMD_SENSOR);
    }

    started = TactileTime_NowUs();
    while (remaining != 0U &&
           (uint32_t)(TactileTime_NowUs() - started) <
               TACTILE_SENSOR_PRIME_TIMEOUT_US)
    {
        for (channel = 0U; channel < TACTILE_CHANNEL_COUNT; ++channel)
        {
            uint8_t ready = 0U;
            uint32_t elapsed;
            if (done[channel] != 0U)
            {
                continue;
            }
            if (!ReadRegister(channel, NSA_REG_DATA_READY, &ready))
            {
                continue;
            }
            if ((ready & NSA_DATA_READY) == 0U)
            {
                continue;
            }
            done[channel] = 1U;
            --remaining;
            elapsed = (uint32_t)(TactileTime_NowUs() - trigger_time_us[channel]);
            if (g_tactile_diag.prime_conversion_us == 0U)
            {
                g_tactile_diag.prime_conversion_us = elapsed;
            }
        }
    }
    g_tactile_diag.prime_timeout = (remaining != 0U) ? 1U : 0U;
}
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

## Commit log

2026-09-11 Tactile500: 四板500Hz触觉采集系统（固件 + PyUSB上位机）
    固件 (APM32F402, Keil/GCC):
    - 双SPI采集，6种板型构建（左/右手 x 12点/32点 x 长/短线）
    - 500Hz UART DMA广播，921600 8N1，V2协议 0x21
    - 左右手由编译期 TACTILE_PROFILE 决定，写入帧内 identity 字节
    上位机 (Python 3.10, PyUSB 1.3.1):
    - 异步 Bulk IN 预提交32请求，四板各约500Hz实测零丢帧
    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
2026-09-11 清理：移除内网IP、修复目录重组导致的失效链接
    - 内网地址替换为 <G1-IP> 占位符（5处），脚本默认值改为 localhost
    - 修复 21 处失效 Markdown 链接（目录提升一层 + 排除 reports/out/备份 导致）
    - 新增 check_links.py：校验全部相对链接（现 81 个全部有效）
    - 重写 README_当前版本.md 与 今晚测试入口 以匹配仓库新结构
    - 标注 audit_pcb_nets.py 依赖仓库外资源
2026-09-11 固件修复：fresh_mask 恒为 0 的根因，改用命令驱动单次转换
    根因（NSA2302 datasheet Rev1.2）:
    - 0xA5 bit7 DAC_on 为 'Enable voltage output mode'（第11页）
    - 原固件写 0xA5=0x88 置 DAC_on=1，进入 6.3 节 analog output mode
    （'no matter what CMD registers contents'，自主 64压力+1温度转换）
    - 而 INT/DRDY 只在 6.5.1 节命令驱动的四种工作模式下定义
    - 该模式不驱动 INT/DRDY，故 fresh_mask 恒为 0（数据仍在更新）
    修复内容:
    - tactile_config.h: 保持 0xA5=0x08 (DAC_on=0)；新增 0x30 COMMAND 寄存器宏；
    SPI 1.875MHz -> 7.5MHz（手册 Table 7.2 上限 10MHz，为新增触发字节留预算）
    - tactile_sensor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
    [tactile_config.h, tactile_sensor.c]
2026-09-11 文档：同步 2026-09-11 固件改动，消除过时描述
    - CHANGELOG_AND_BENCH_PLAN.md: 在'当前嵌入式配置'表前加日期更新表，
    列出 SPI(1.875->7.5MHz)、OSR(2048->256)、0xA5(0x88->0x08)、
    采集时序(盲读->流水线)四项变更的新旧对照
    - 原表 SPI1/SPI2 两行加 '已变更' 标记，避免读者误用
    - 验收阶段 B 的 SPI 判据更新为 7.5MHz（保留历史值）
    - 验收阶段 F 注明 fresh_mask 自 2026-09-11 起才真正可用
2026-09-11 固件 v2：SPI 降至 3.75MHz 修复初始化失败 + 初始化诊断
    v1（7.5MHz）实机结果（G2 四板 120 秒）:
    - DRDY 修复成功：可用通道 fresh_mask 不再恒为 0
    - 关键发现：所有可用通道 fresh 比例精确 = 0.5000
    => 单次模式一次完整转换（含 power-up）耗时 2~4ms
    => 500Hz 帧率下真实新转换约 250Hz
    => 这解释了模拟输出模式为何能到 489/秒（自主连续、无上电开销）
    - 问题：init_error 出现在所有板，失败集中在 channel < COUNT/2（SPI1 侧）
    右12 ch0-5、左12 ch0-6、右/左32 ch0-7
    判定 32 片并联总线在 7.5MHz 下信号完整性不足
    v2 改动:
    - tactile_config.h: SPI1 /16->/32、SP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
    [tactile_config.h, tactile_sensor.c]
2026-09-11 固件 v3：运行中自愈，解决初始化失败/fresh 恒0
    背景（v1/v2 实测）:
    - v1(7.5MHz): DRDY 修复成功(可用通道 fresh=0.5)，但 SPI1 侧通道 init 失败
    - v2(3.75MHz): G2 实测 init_error 仍存在，失败仍集中在 SPI1 侧
    => 单纯降 SPI 速率不是根本原因
    新推断:
    - 板载 EEPROM 被早期固件烧入 0xA5=0x88(模拟输出模式)
    - 上电 EEPROM 自动加载 0x88；固件再写 0x08 切换模式
    - 若该写入未生效，芯片留在模拟输出模式，写 0x30 触发命令被忽略
    (datasheet 6.3 'no matter what CMD registers contents')，DRDY 永不置位
    - 这一个原因同时解释 init 校验失败与 fresh 恒 0
    v3 改动:
    - 运行中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
    [tactile_config.h, tactile_sensor.c]
2026-09-11 整理：删除多余 HEX 交付目录，文档并入 docs/
    按用户要求：Keil 工程本身即编译最新源码，不需要额外 HEX 目录。
    - 删除 烧录_DRDY修复_20260911、烧录_v3_20260911（我创建的两个目录）
    - 保留 烧录_OSR256_20260910（用户原始交付 + 回退路径）
    - 新增 docs/DRDY修复与v3自愈记录.md，汇总根因、版本演进、
    自愈机制、诊断量、EEPROM 标定寄存器地图
    - CHANGELOG 链接改指 docs/ 内文档，无残留引用
    烧录路径：打开 Project/MDK/Tactile500.uvprojx -> 选 Target -> Build
    产物：build/keil/<Target>/Tactile500_<Target>.hex
2026-09-11 v3 实机验证通过：全部通道恢复，fresh_mask 问题彻底解决
    G2 实机结果（四板，10 秒 probe）:
    - init_error: 100% 帧 -> 0/4964，完全消失
    - fresh 为 0 的通道: 50 个 -> 0 个
    - fresh 正常通道: 32/32, 12/12, 32/32, 12/12 全部
    - 帧率 500Hz, missing/dup/drop 均为 0
    - status 仅剩 not_all_fresh
    - 本次接长线版 32 点板(id 0x0A/0x0B)，身份识别全部正确
    关键结论:
    - fresh ≈ 0.5 是健康值，源于单次转换耗时 2~4ms > 2ms 帧周期
    - 一个病根同时解释 init 失败与 fresh 恒 0：EEPROM 烧入 0xA5=0x88，
    上电若 0xA5=0x08 写入未生效，芯片留在模拟输出模式，
    0x30 触发命令被忽略，DRDY 永不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
2026-09-11 新增软件校零（tare）0.4.0：采集前校零 + 原始值保留 + 漂移回溯
    设计三原则:
    1. 原始值永不修改 —— frame.pressure 始终是固件原值，校零只是视图
    2. 每次校零留档 —— 追加式 JSONL，可事后统计多天零点漂移
    3. 坏通道不静默处理 —— 饱和/无数据通道给 0 偏移并明确标记
    新增 tactile500/tare.py:
    - measure_baseline(): 自开订阅采 1~3s 基线，不影响调用方自己的订阅
    通道状态四档: ok / unstable / saturated / no_data
    偏移取中位数（本系统有满量程尖峰，均值会被拉偏）
    稳定性只用 fresh_mask 命中帧评估（非 fresh 是重复值，会低估波动）
    - Ta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
2026-09-11 修正：还原被本地构建覆盖的 0.3.0 wheel
    问题：构建 0.4.0 之前，本地曾用当时的源码（已含 tare.py）重新构建过一次
    0.3.0，把 wheelhouse 里的原始 0.3.0 交付件覆盖成了内容不一致的版本。
    （同一版本号、不同内容，会误导使用方。）
    处理：从首个提交 55cd6e3 检出原始 0.3.0 wheel，SHA-256 校验通过
    E029885B... -> 91C3FFF10F87303007847D0737833BD6A8B09C4B6C0409A24B038F63D1F4A0C9
    并确认其中不含 tare.py（tare 属 0.4.0）
    同步：原始项目 gpt6-tactile500_pyusb上位机/wheelhouse/ 也已还原
2026-09-11 命名统一 0.4.1：主函数改名 tare_now，全套 tare_* 前缀
    问题：四个东西里三个带 Tare 前缀，只有主函数叫 measure_baseline，
    搜 tare 找不到它，搜 measure 又太泛，不便辨认。
    改动（搜 tare 现在能一网打尽）:
    tare_now() 主函数（唯一入口）——原 measure_baseline
    TareResult 一次校零的完整结果
    TareFilter 应用到实时帧
    TareJournal 追加式档案
    ChannelBaseline 单通道基线统计
    restore() 还原成原始值
    tactile500.tare 模块
    docs/TARE.md 文档
    tools/tare_journal.py CLI
    兼容: measure_baseline 保留为 tare_now 的别名，0.4.0 调用方不受影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
2026-09-11 文档：新增《软件校零（Tare）模块交付报告》
    面向系统集成方与系统文档编写，含:
    - 需求来源（三条要求）
    - 设计三原则与关键技术决策及理由
    - 接口清单与三步集成示例
    - 实机验证数据（G2 四板 88 通道，tactile500 0.4.1）
    基线: 87 通道 ok，left_fingers ch0 饱和被正确跳过并告警
    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
2026-09-11 0.4.2：新增 tare 命令行（软件校零），pyproject 注册入口
    - pyproject.toml：[project.scripts] 加一行 tare = "tactile500.tare:main"，版本 0.4.1 → 0.4.2
    - src/tactile500/tare.py：新增 build_parser() / main()，支持 --seconds --roles --note
    --journal --no-journal --out --simulate --indent --quiet；退出码 0 成功 / 1 未采到板 / 130 中断
    - tests/test_tare.py：新增 5 项 CLI 用例（含“入口必须注册且指向可调用函数”守护测试），全量 29 passed
    - docs/TARE.md、README.md：补 tare 命令用法、退出码与 0.4.2 安装说明
    - wheelhouse：新增 tactile500-0.4.2-py3-none-any.whl
2026-09-11 outline：新增二维采样点与三维结构模型
    二维采样点 outline/2d_sampling_points/
    - sensor_coords.py：12 点 / 32 点板坐标常量模块，含「左下角 = (0, 0)」
    的原点化坐标与原始绝对坐标两套，派生量全部由原始表推导
    - coord_Big_raw.csv / coord_Small_raw.csv：原始坐标（逐字保留）
    - 传感器坐标图.md：嵌入 PNG + 纯文本 ASCII 坐标图 + 逐行坐标表 + 结构分析
    - coord_plot_*.png：三张等比例坐标图，生成时校验 ratio=1.0000 且说明框不遮挡数据点
    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
    [Connector_illustrative.step, PCB_illustrative.step, Silicone_cap.step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]
2026-09-11 整理：修正根 README 的仓库结构树与安装版本号
    - 结构树补上此前缺失的 outline/ 与 docs/，并补全 firmware 的烧录交付目录
    - 安装命令 tactile500==0.3.0 -> 0.4.2（wheelhouse 当前版本），共 2 处
